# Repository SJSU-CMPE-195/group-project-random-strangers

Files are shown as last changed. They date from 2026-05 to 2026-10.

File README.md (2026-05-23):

# Project Title

> Automatic Dodgeball Turret for Defence and ATTACK!

## Team

| Name | GitHub | Email |
|---|---|---|
| Zoya Shamak | [@ZoyaS](https://github.com/ZoyaS) | zoya.shamak@sjsu.edu |
| Isa Pudiyapura | [@github210878](https://github.com/github210878) | isa.pudiyapura@sjsu.edu |
| Eric Huang | [@eiechuang](https://github.com/eiechuang) | eric.huang01@sjsu.edu |
| Brendan Parvin | [@brendanofawesome](https://github.com/Brendanofawesome) | brendan.parvin@sjsu.edu |

**Advisor:** [Prof. Wencen Wu]

---

# Project Design  

## Problem Statement  

**Dodgeball is a timeless game of skill and agility. We hope to fix that!**  
With our turret, no longer do you need any particular ability in order to:
 - aim and fire dodgeballs at targets
 - automatically defend against incoming dodgeballs using *hit-to-kill* 

## Proof of Concept Scope

Demonstrate a design that includes:

- [ ] **Fully working mechanical system**
    - [ ] Gimbal with control in both yaw and roll orientations
    - [ ] Flywheel-based dodgeball launching system

- [ ] **Control system for setting motor parameters**
    - [ ] Webserver interaction
    - [ ] I2C-based configuration of ESC drivers
    - [ ] Parameters persist across resets

- [ ] **Targeting and firing system**
    - [ ] Webserver integration to select point on screen
    - [ ] Trajectory estimation

---

# Implementation  

## Screenshots  
| Feature | Screenshot |
|---|---|

## Tech Stack

| Description | Category | Technology | Running On |
|---|---|---|---|
| Command and control webserver | Frontend | Next.JS | Jetson |
| Depth Sensing | Sensing | Microsoft Kinect 2 with libfreenect2 | Jetson |
| High Speed BLDC Control | Movement | SimpleFOC | ESCs |

## Getting Started  
 **TODO** Add a tutorial to getting all the parts working :)  

---

## License

This project is licensed under the [LGPLv3 License](www.gnu.org/licenses/lgpl-3.0.en.htm) - see the [LICENSE](LICENSE.md) file for details.

---

*CMPE 195A/B - Senior Design Project | San Jose State University | Spring 2026*

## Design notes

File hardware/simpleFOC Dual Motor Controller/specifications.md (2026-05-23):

# SimpleFOC Dual Motor Controller - Specifications

## Overview
High-performance dual BLDC motor driver with FOC (Field-Oriented Control) algorithm support, designed for applications requiring precise motor control with simultaneous dual-motor operation.

---

## Power Specifications

### Input Power
- **Voltage Range**: 0V - 36V (nominal 36V maximum)
- **Continuous Power**: As determined by thermal dissipation and current limits (IDK)
- **Voltage Input Protection**: 
  - [x] Overvoltage protection (TVS diodes or Zener clamps)
  - [ ] Reverse polarity protection (ideal diode or integrated FET)
  - [ ] Surge suppression for inductive loads

### Current Specifications
- **Continuous Current per Motor**: 35A (per motor pole)
- **Peak Continuous Current**: 64A (per motor pole)
- **Current Sense Method**: integrated low side current sensing per pole
- **Current Limiting**: Software-controlled with adjustable thresholds

### Power Dissipation
- **MOSFET Losses**: 35A * 4mΩ * 2 = 0.28W per pole
- **Thermal Management**: Heat sinks required for continuous high-current operation
- **Thermal Shutdown**: Integrated temperature monitoring with cutoff at 80-85°C

---

## Motor Control Features

### Supported Motor Types
- **Primary**: 3-phase BLDC (Brushless DC) motors
- **Motor Poles**: 2 to 12 pole pairs typical range
- **Motor Power Range**: 0W to 3kW (voltage and current dependent)

### Encoder/Sensor Support
- **Hall Effect Sensors**:
  - Support for all Hall configurations (commutation angles)
  - Automatic Hall state detection and phase alignment
  
- **Encoder Interface**:
  - Dedicated input pins per motor for Hall sensor signals
  - Hardware debouncing (optional RC filters)
  - Software debounce filtering with configurable delay

### Control Algorithms
- **FOC (Field-Oriented Control)**: Primary control mode
- **Commutation**: Hall-based 6-step or smooth vector control
- **Velocity Control**: PID-based speed regulation
- **Current Control**: Inner PID loop for precise current management
- **Position Control**: Incremental position tracking

---

## Hardware Architecture

### Motor Driving Stage (Per Motor)
- **Topology**: 3-phase full-bridge (6-MOSFET inverter)
- **Gate Driver**: discrete high/low-side gate drivers
  - Deadtime compensation to prevent cross-conduction
  - Bootstrap capacitor charging for high-side drivers
  - Shoot-through protection
  
- **Power Semiconductors**:
  - N-channel MOSFETs with low RDS(on) (<4mΩ typical at 25°C)
  - Voltage rating: ≥60V to handle transient spikes
  - Current rating: ≥50A continuous (per phase)

### Current Sensing (Per Motor)
- **Method**: Low-side shunt resistor sensing
- **Shunt Resistance**: Typical 0.001Ω - 0.01Ω (precision resistor ±1%)
- **Current Signal Processing**:
  - Op-amp based amplification and filtering
  - Signal level conversion to ADC-compatible range (0-3.3V)
  - DC offset rejection and noise filtering

### Hall Sensor Interface
- **Input Impedance**: High impedance (pull-up to 3.3V or 5V)
- **Debouncing**: Hardware (RC filter, typically 1-10µs time constant)
- **Signal Conditioning**: Schmitt trigger inputs for noise immunity
- **Per-Motor Configuration**: Independent hall input pins for dual-motor operation

### Microcontroller/Controller Board
- **Integrated Microcontroller**: 
  - **STM32G4 Series**: Cost-effective FOC control with sufficient processing power for dual motor management

### Power Distribution
- **Input Filtering**:
  - Bulk capacitance: 220µF @ 100V
  - High-frequency ceramic capacitors: 10uF x 12
  - LC filtering for noise reduction
  
- **Voltage Rails**:
  - Main power bus: +36V (directly from input)
  - Logic supply: +5V
  - Gate driver supply: 10V Charge Pump

---

## Electrical Specifications

### Output Specifications (Per Motor)
- **Output Voltage**: 0V - VIN (PWM modulated)
- **Frequency**: 16-20 kHz typical (configurable)
- **Phase Current Range**: 0A - 35A (continuous)

### Protection Features
- **Over-Current Protection**: Software-programmable limits per motor
- **Over-Temperature**: Thermal shutdown with hysteresis
- **Phase Fault Detection**: Open-phase or short-circuit detection
- **Under-voltage Lockout**: Prevents operation below safe voltage threshold
- **Over-voltage Clamping**: TVS diodes on phase outputs

### Control Signals
- **PWM Frequency**: 16-20 kHz (20-25 kHz for low audible noise)
- **Deadtime**: 50-200ns (tunable to minimize losses and cross-conduction)
- **Switching Resolution**: 12-bit typical (configurable)

---

## Communication Interface

### I2C Slave Interface
- **Protocol**: I2C slave
- **Clock Speed**: Up to 800 kHz (configurable)
- **Data Width**: 8-bit transfers
- **Features**:
  - Real-time motor control commands
  - Telemetry readback (speed, current, temperature)
  - Parameter configuration and tuning
  - Fault/diagnostic reporting and clearing
  - Low latency (<1ms round-trip response)

### Backup Communication
- **USB Debug Port**: 115200 baud for development/debugging only
- **Protocol**: UART for system diagnostics

### Configuration
- **Parameter Storage**: Flash memory for persistent settings
- **Firmware Updates**: Via USB interface with checksumming
- **Startup Calibration**: Automated hall sensor calibration on power-up or via SPI command

---

## Performance Specifications

### Control Performance
- **Current Control Loop Frequency**: 10-20 kHz
- **Velocity Control Loop Frequency**: 1-5 kHz (configurable)
- **Current Ripple**: <5% at rated current
- **Efficiency**: >90% at rated current (at 36V input)

### Sensor Performance
- **Hall Sensor Polling Rate**: 20 kHz minimum
- **Hall-to-PWM Update Latency**: <100µs
- **Motor Startup Time**: <500ms from initialization to controlled rotation

---

## Thermal Management

### Temperature Monitoring
- **Sensor Location**: On heatsink or MOSFET thermal pad
- **Temperature Range (Operating)**: -10°C to +85°C
- **Temperature Range (Storage)**: -20°C to +100°C
- **Thermal Shutdown**: 80-85°C (with 5-10°C hysteresis)

### Cooling Requirements
- **Passive Cooling**: Adequate heatsinks for 35A continuous operation
- **Active Cooling**: Optional fan control for high-duty-cycle applications
- **Thermal Design**: Capable of dissipating >600W continuously

---

## Physical and Mechanical

### PCB Design
- **Layer Count**: 4-layer minimum (power, ground planes essential)
- **Trace Width**: Calculated for 35A+ with <10mV drop per phase
- **Thermal Vias**: Liberally used under MOSFET pads and power components
- **Isolation**: 3kV reinforced isolation between control and power sections (optional)

### Connector Standards
- **Power Input**: High-current connector (XT60, XT90, or Anderson PowerPole)
- **Motor Output**: 3.5mm or 5mm phoenix connectors per motor
- **Hall Sensors**: JST-XH or similar low-current connectors (6 pins per motor)
- **Communication**: USB micro-B or UART header

### Dimensions
- **Target Size**: ~150mm × 100mm × 50mm (estimated, depends on heatsink size)
- **Weight**: <500g (without heatsink)

---

## Software Architecture

### Firmware Platform
- **Framework**: simpleFOC library v2.3+ with dual-motor support
- **Development Language**: C/C++

### Core Control Loop
- **Execution**: Hardware timer interrupt (20 kHz)
- **Tasks**:
  1. Read hall sensor states
  2. Estimate rotor angle via sensor fusion
  3. Calculate FOC voltage vectors
  4. Update PWM outputs
  5. Log telemetry (if enabled)

### Tuning Parameters
- **PID Gains** (per motor):
  - Current loop: Kp, Ki (typically Kp=10-50, Ki=100-500)
  - Velocity loop: Kp, Ki, Kd
- **Motor Parameters**: Pole pairs, voltage rating, current rating
- **Hall Configuration**: Specific angle mapping for hall state transitions

---

## Compliance and Safety

### Electrical Safety
- **Isolation**: Optional galvanic isolation between control and power circuits
- **Fusing**: Input fuse rated for 40-50A @ 48V (protection from short-circuit)
- **Creepage/Clearance**: PCB design follows IEC standards

### Functional Safety
- **Watchdog Timer**: Monitors firmware execution and resets on timeout
- **Redundant Checks**: Current and temperature limits with independent enforcement
- **Fault Reporting**: Detailed error codes for diagnostics and debugging

---

## Typical Applications

- Dual-axis robotic actuators
- Autonomous vehicle drive systems
- High-performance drone motors
- Gimbal stabilization systems
- Industrial automation drives

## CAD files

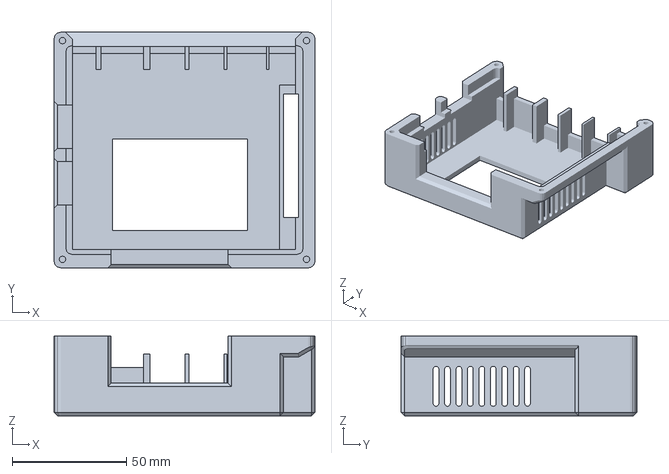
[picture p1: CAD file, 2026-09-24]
hardware/3D Models/Jetson/Orin_nano_case_main_No_CAN_No inserts.3MF
114.0 x 103.0 x 34.8 mm

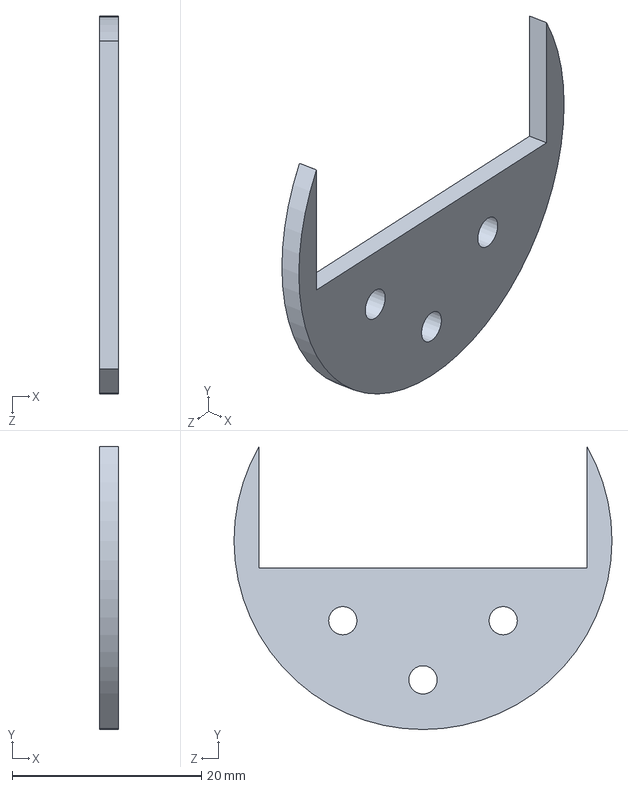
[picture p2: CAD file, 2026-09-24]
hardware/3D Models/Gimbal/3d_printed - depreciated/Magnet Plate Spacer.SLDPRT
2.00 x 29.9 x 40.0 mm

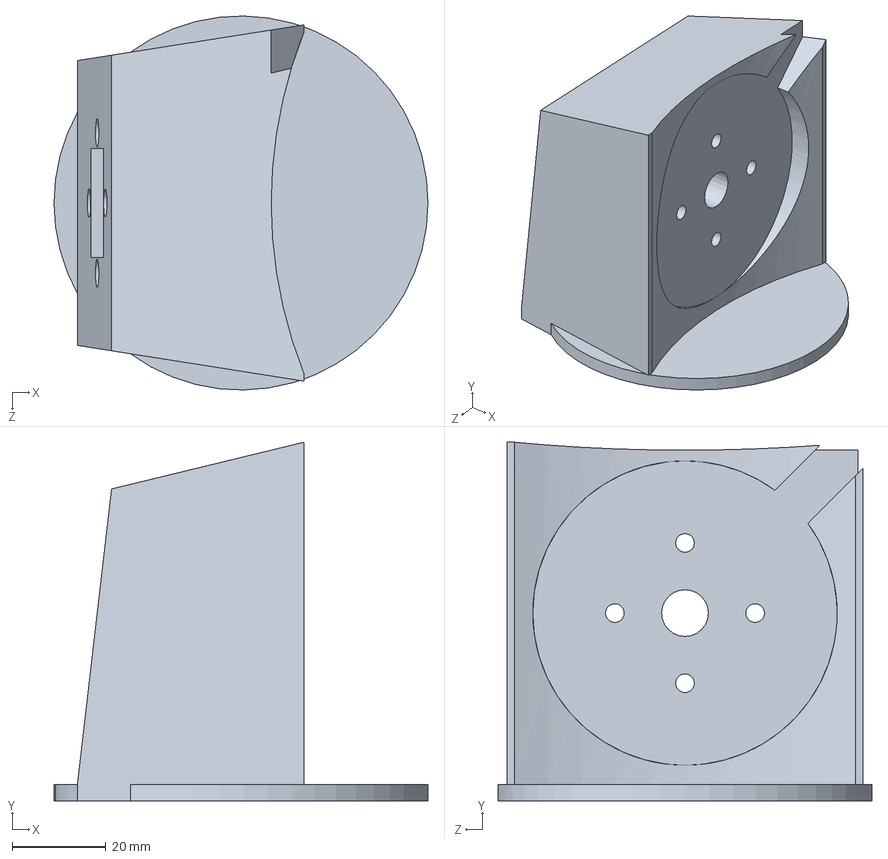
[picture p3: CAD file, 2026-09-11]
hardware/3D Models/Gimbal/Test Stands/Pitch Motor Test Stand.SLDPRT
80.0 x 76.7 x 80.0 mm

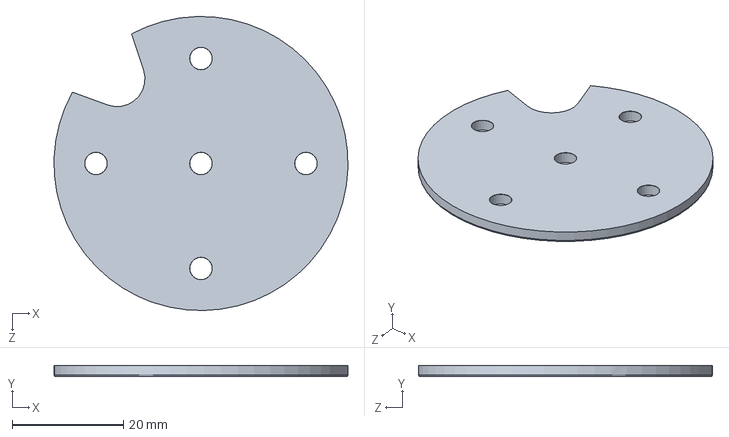
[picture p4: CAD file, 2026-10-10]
hardware/3D Models/Gimbal/wood/Slip Ring Hole Guide.SLDPRT
52.8 x 2.00 x 52.8 mm

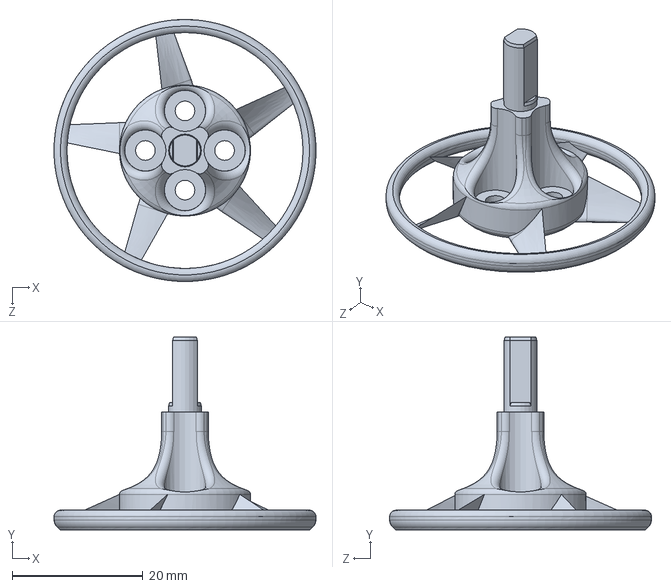
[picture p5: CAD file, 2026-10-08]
hardware/3D Models/Launcher/Flywheels/Flywheel Wheel Mount.SLDPRT
40.0 x 29.4 x 40.0 mm

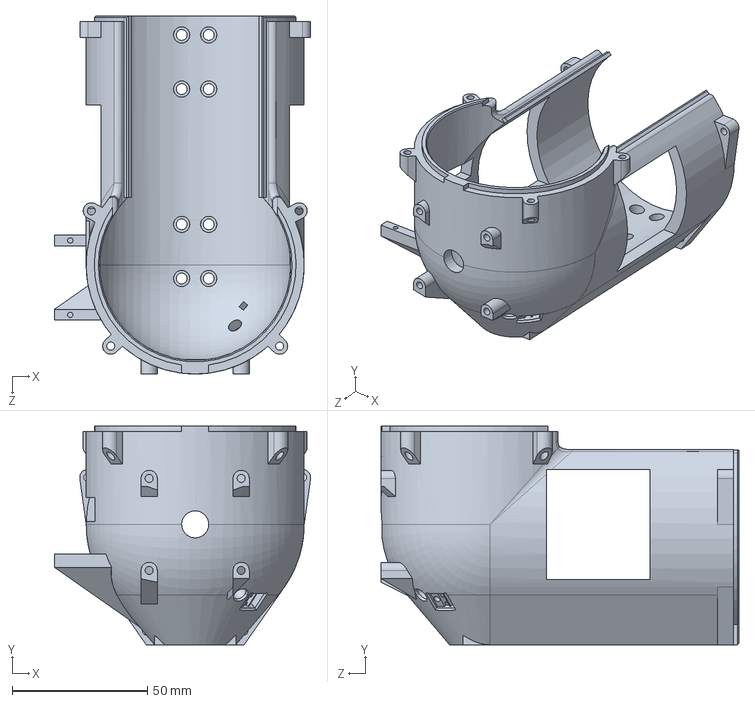
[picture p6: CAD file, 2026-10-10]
hardware/3D Models/Launcher/Load Mechanism/Stager.SLDPRT
94.7 x 80.8 x 132.3 mm

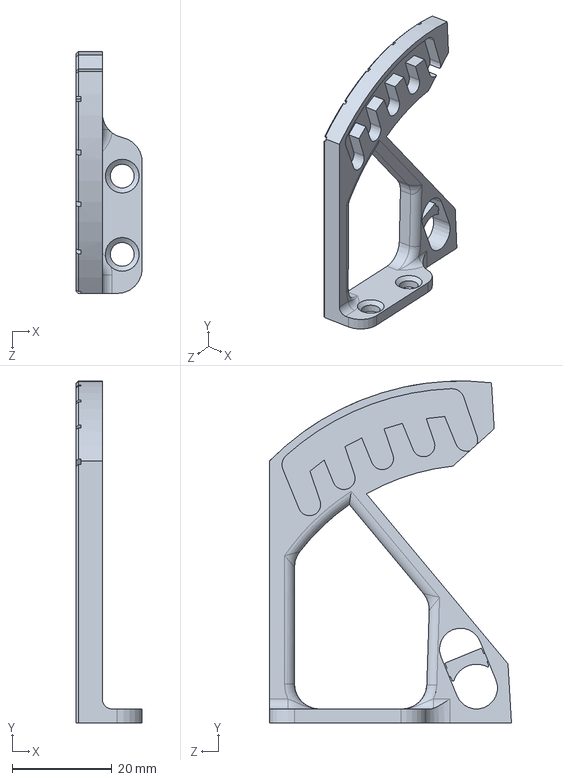
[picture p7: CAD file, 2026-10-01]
hardware/3D Models/Mounts/Zed Mount/Zed Angle Guage.SLDPRT
13.3 x 68.4 x 48.4 mm

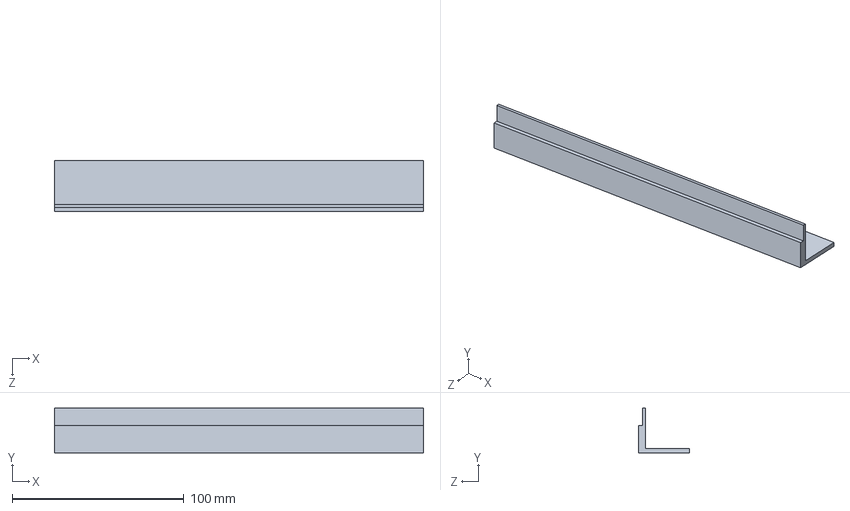
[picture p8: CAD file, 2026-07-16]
hardware/3D Models/Power Supply/Power Supply.SLDPRT
215.0 x 26.0 x 30.0 mm

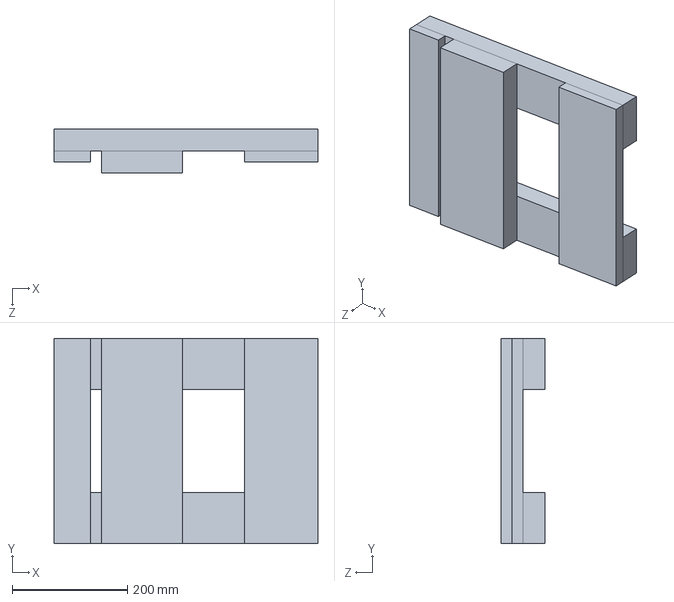
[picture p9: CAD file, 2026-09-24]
hardware/3D Models/Base.SLDPRT
457.2 x 355.6 x 76.2 mm

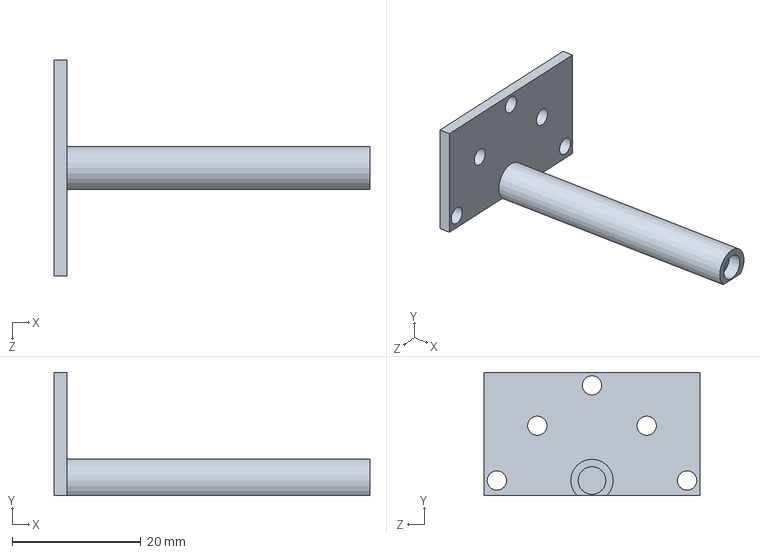
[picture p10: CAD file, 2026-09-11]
hardware/3D Models/Gimbal/3d_printed - depreciated/Pitch Motor Magnet Plate.SLDPRT
49.0 x 19.1 x 33.5 mm

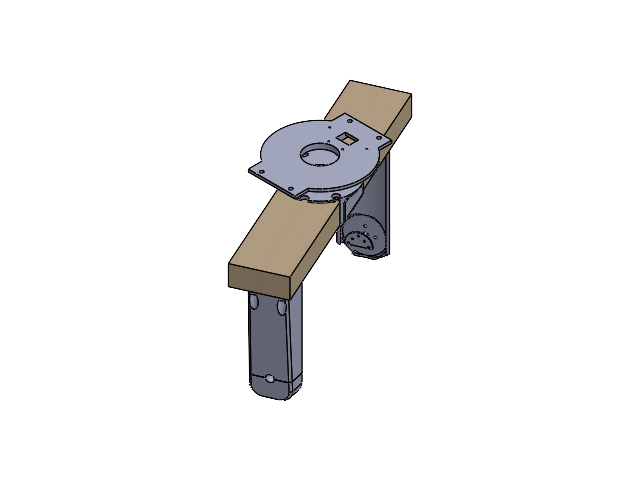
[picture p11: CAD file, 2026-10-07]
hardware/3D Models/Gimbal/Gimbal.SLDASM
Gimbal Base
Yaw Flush Plate
Yaw Beam
Pitch Motor Magnet Plate - wood
Pitch Mount - Bearing
Pitch Mount - Motor

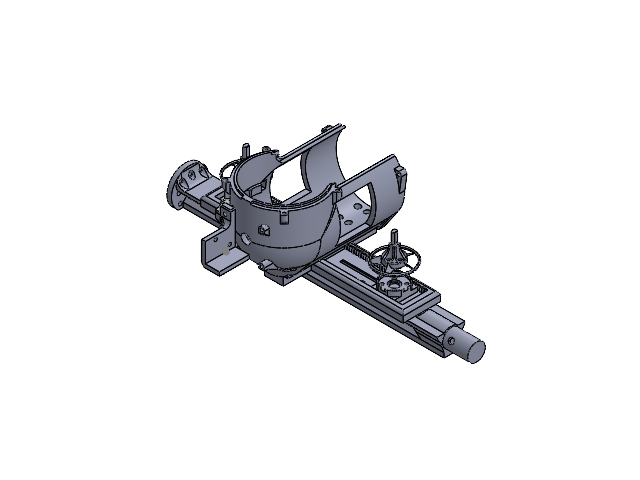
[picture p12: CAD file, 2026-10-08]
hardware/3D Models/Launcher/Launcher Assembly.SLDASM
Launcher I-Beam Mount
Bearing End Mount^Launcher Assembly
Flywheel Rail
Flywheel Motor Mount x 2
Stager
SG90 - Micro Servo 9g - Tower Pro.1_Pe_a.STEP
Loader Stop
Solenoid Mount
Flywheel Wheel Mount
MirrorFlywheel Wheel Mount

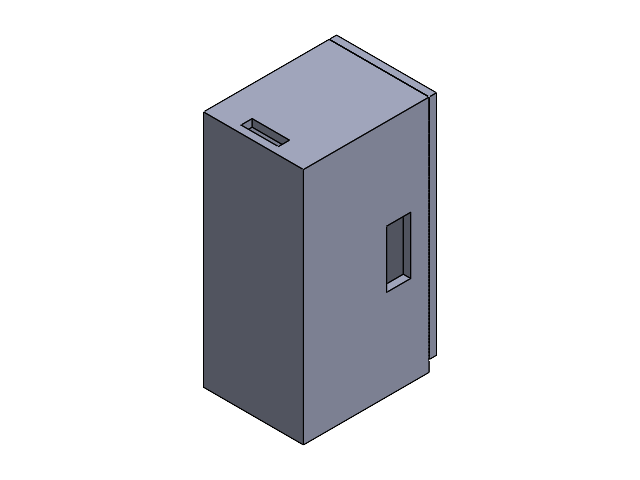
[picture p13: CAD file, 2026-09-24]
hardware/3D Models/Mounts/Yaw Motor/Yaw Motor Box.SLDASM
Box Bottom
Box Top

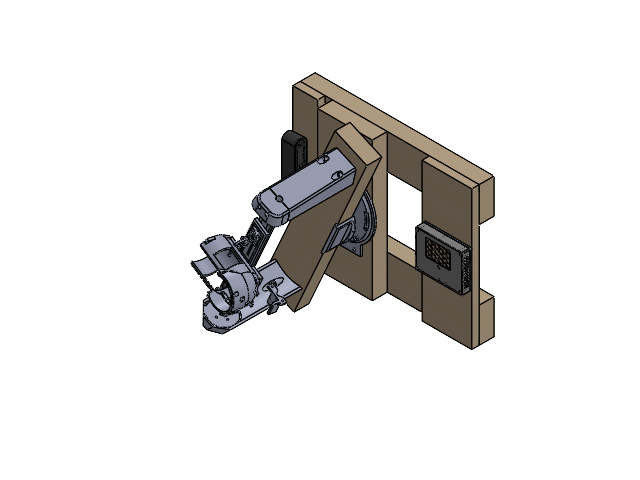
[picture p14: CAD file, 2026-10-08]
hardware/3D Models/Turret.SLDASM
Base
DSL958R-650-F2.0 -光锥图.step x 2
Narrow lens 4.6mm.step x 2
Right Lens Holder.step x 2
PCB ZED2i.step
USB Type C Port.step
Front case - ZED 2i.step
Rear case - ZED 2i.step
Camera Component - Body - ZED 2i - 4.6mm - Cover.step
Gimbal Base
Yaw Flush Plate
Yaw Beam
Pitch Motor Magnet Plate - wood
Pitch Mount - Bearing
Pitch Mount - Motor
orin-nano-case-base.step
orin-nano-case-top.step
Launcher I-Beam Mount
Bearing End Mount^Launcher Assembly
Flywheel Rail
Flywheel Motor Mount x 2
Stager
SG90 - Micro Servo 9g - Tower Pro.1_Pe_a.STEP
Loader Stop
Solenoid Mount
Flywheel Wheel Mount x 2

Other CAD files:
hardware/3D Models/Gimbal/3d_printed - depreciated/Gimbal Assembly.SLDASM
hardware/3D Models/Launcher/Load Mechanism/Loader Assembly.SLDASM
hardware/3D Models/Mounts/Zed Mount/Zed Mount.SLDASM
hardware/3D Models/Launcher/Flywheels/Flywheel Assembly.SLDASM
hardware/3D Models/Gimbal/3d_printed - depreciated/Gimbal Pivot Holder.SLDPRT
hardware/3D Models/Gimbal/3d_printed - depreciated/Gimbal Swivel.SLDPRT
hardware/3D Models/Gimbal/Gimbal Base.SLDPRT
hardware/3D Models/Gimbal/wood/Gimbal Bearing Mount Bottom.SLDPRT
hardware/3D Models/Gimbal/wood/Gimbal Bearing Mount Top.SLDPRT
hardware/3D Models/Gimbal/wood/Pitch Motor Magnet Plate - wood.SLDPRT
hardware/3D Models/Gimbal/wood/Pitch Mount - Bearing Bottom.SLDPRT
hardware/3D Models/Gimbal/wood/Pitch Mount - Bearing.SLDPRT
hardware/3D Models/Gimbal/wood/Pitch Mount - Motor.SLDPRT
hardware/3D Models/Gimbal/wood/Yaw Beam.SLDPRT
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

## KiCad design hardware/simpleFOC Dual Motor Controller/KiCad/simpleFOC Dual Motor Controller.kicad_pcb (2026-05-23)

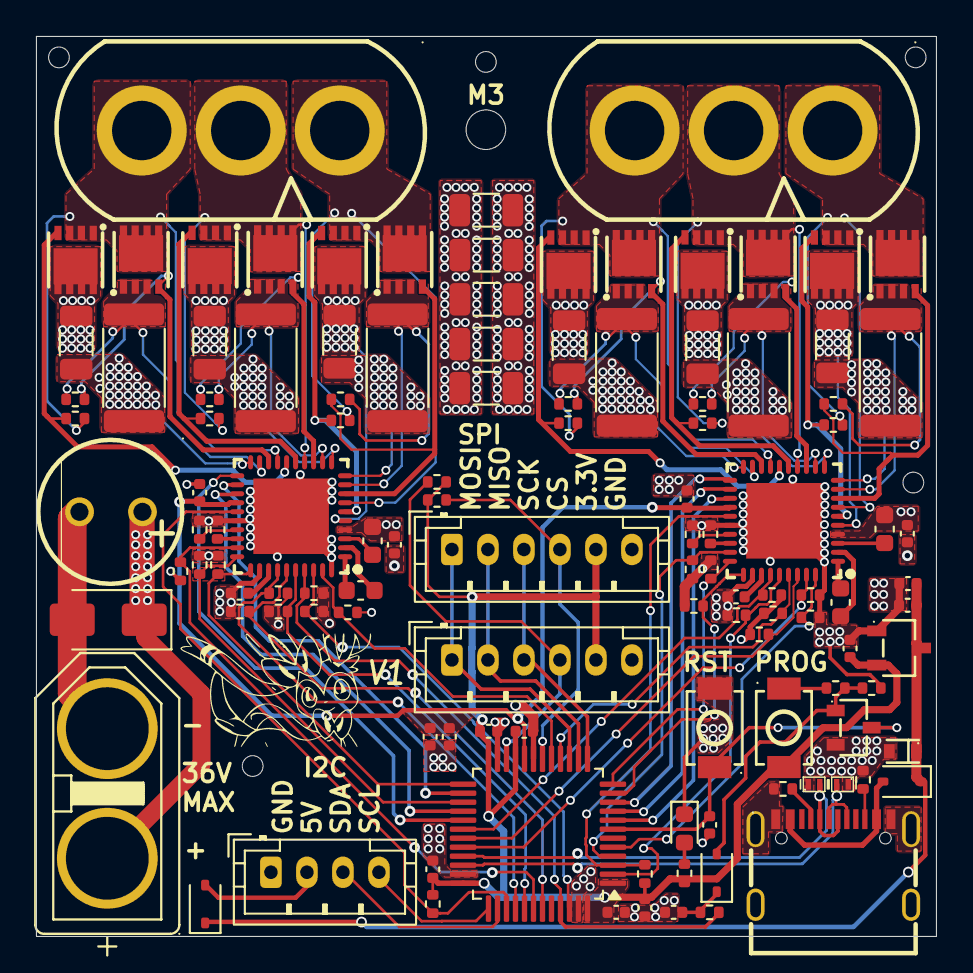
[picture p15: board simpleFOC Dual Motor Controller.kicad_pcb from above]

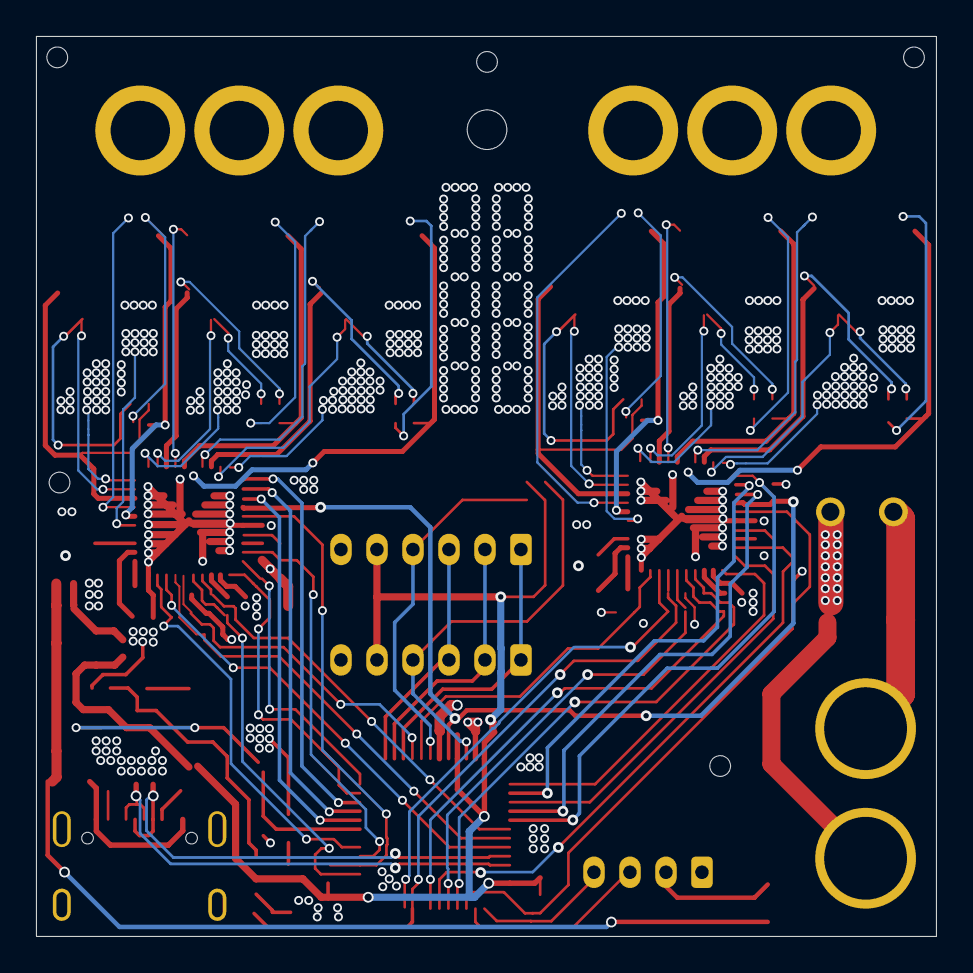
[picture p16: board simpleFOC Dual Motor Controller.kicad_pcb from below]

Board: 4 copper layers, 50.0 x 50.0 mm, 130 parts (6 on the bottom side), 91 nets.

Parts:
C101: 220u; CAP-TH_BD8.0-P3.50-D0.6-FD
C102, C115: 4.7u; C_0402_1005Metric
C103, C104, C106, C107, C113, C201, C205, C206, C209: 100n; C_0402_1005Metric
C105, C112, C114, C204, C210: 1u; C_0402_1005Metric
C108, C109, C110, C117, C118, C119, C120, C121, C301, C401, C501: 10u; C_1206_3216Metric
C111: 10n; C_0402_1005Metric
C116: 220n; C_0402_1005Metric
C202, C207: 1u; C_0603_1608Metric
C203, C208: 47n; C_0603_1608Metric
CN101: XT60PB-F.G.Y; CONN-TH_XT60PB-F.G.Y
CN201, CN202: MR60-F; CONN-TH_3P-P5.50_MR60-F
D101: SMAJ36A; D_SMA
D102, D104, D107: 1N5819WS; D_SOD-323
D103, D105: H5VL10B; SOD-882_L1.0-W0.6-BI
D106: LED; LED_0603_1608Metric
H101, H102, H103, H104, H107: MountingHole; JLC_Tooling_Hole
H105: MountingHole; MountingHole_2.2mm_M2
J101: Conn_01x04; JST_PH_B4B-PH-K_1x04_P2.00mm_Vertical
J103, J104: Conn_01x06; JST_PH_B6B-PH-K_1x06_P2.00mm_Vertical
J105: USB-TYPE-C-019; TYPE-C-SMD_HX-TYPE-C-16PIN
NT201, NT202, NT203, NT204, NT205, NT206: NetTie_2; NetTie0.127mm
Q101: AO3400A; SOT-23-3_L2.9-W1.3-P1.90-LS2.4-BR
Q301, Q302, Q401, Q402, Q501, Q502, Q701, Q702, Q801, Q802, Q901, Q902: XRS100N06LD; DFN-8_L3.0-W3.0-P0.65-BL-4
R101, R102, R103, R104, R105, R106, R223, R301, R302, R401, R402, R501, R502, R601: 47k; R_0402_1005Metric
R107, R108: 5.1k; R_0402_1005Metric
R109, R113: 3.3k; R_0402_1005Metric
R110, R111, R112, R203, R204, R205, R206, R207, R208, R209, R210, R211, R214, R215, R216, R220, R221, R222, R602, R603, R604: 100k; R_0402_1005Metric
R114: 330; R_0402_1005Metric
R201, R213: 18k; R_0402_1005Metric
R202, R212: 75k; R_0402_1005Metric
Rsns101, Rsns102, Rsns103, Rsns301, Rsns401, Rsns501: 0.002; R_2512_6332Metric
SW101, SW102: TS-1088-AR02016; SW-SMD_L3.9-W3.0-P4.45
U101: XC6206P332MR; SOT-23-3_L2.9-W1.6-P1.90-LS2.8-BR
U103: STM32G474CBTx; LQFP-48_7x7mm_P0.5mm
U104: H5VND5UB; SOD-523F_L1.7-W0.9-LS1.7-RD
U201, U202: DRV8323HRTAT; WQFN-40_L6.0-W6.0-P0.50-TL-EP4.2

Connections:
+3.3V: C103.1, C104.1, C106.1, C107.1, C112.1, C115.1, J103.5, J104.5, R110.2, R111.2, R114.1, R211.2, R222.2, SW102.1, U101.2 (Vout), U103.1 (VBAT), U103.21 (VDDA), U103.24 (VDD), U103.36 (VDD), U103.48 (VDD)
+5V: C102.1, C105.1, D102.1 (K), D107.1 (K), U101.3 (Vin), U104.1 (K)
/CAL1: R210.1, U103.11 (PA3), U201.31 (CAL)
/CAL2: R221.1, U103.25 (PB11), U202.31 (CAL)
/CHA1: R203.1, U103.30 (TIM1_CH1), U201.34 (INHA)
/CHA2: R214.1, U103.40 (TIM8_CH1N), U202.34 (INHA)
/CHB1: R204.1, U103.16 (TIM1_CH2N), U201.36 (INHB)
/CHB2: R215.1, U103.41 (TIM8_CH2N), U202.36 (INHB)
/CHC1: R205.1, U103.32 (TIM1_CH3), U201.38 (INHC)
/CHC2: R216.1, U103.46 (TIM8_CH3), U202.38 (INHC)
/CHLA1: R206.1, U103.2 (TIM1_CH1N), U201.35 (INLA)
/CHLA2: R602.1, U103.43 (TIM8_CH1), U202.35 (INLA)
/CHLB1: R207.1, U103.31 (TIM1_CH2), U201.37 (INLB)
/CHLB2: R109.1, R603.1, U103.45 (TIM8_CH2), U202.37 (INLB)
/CHLC1: R208.1, U103.5 (TIM1_CH3N), U201.39 (INLC)
/CHLC2: R604.1, U103.17 (TIM8_CH3N), U202.39 (INLC)
/D+: D103.2 (A), J105.A6 (D+), J105.B6 (D+), U103.34 (USB_DP)
/D-: D105.2 (A), J105.A7 (D-), J105.B7 (D-), U103.33 (USB_DM)
/EN1: R209.1, U103.12 (PA4), U201.30 (ENABLE)
/EN2: R220.1, U103.27 (PB13), U202.30 (ENABLE)
/FAULT1: R211.1, U103.3 (PC14), U201.25 (nFAULT)
/FAULT2: R222.1, U103.39 (PA15), U202.25 (nFAULT)
/GAIN1: R223.1, U103.4 (PC15), U201.29 (GAIN)
/GAIN2: R601.1, U103.42 (PB5), U202.29 (GAIN)
/Motor Driver 1/DVDD: C204.1, U201.33 (DVDD)
/Motor Driver 1/Pole 1/GH: Q302.4 (G), R302.1, U201.6 (GHA)
/Motor Driver 1/Pole 1/GL: Q301.4 (G), R301.1, U201.8 (GLA)
/Motor Driver 1/Pole 1/PoleOut: CN201.1, Q301.5 (D), Q302.1 (S), Q302.2 (S), Q302.3 (S), R302.2, U201.7 (SHA)
/Motor Driver 1/Pole 1/SP: Q301.1 (S), Q301.2 (S), Q301.3 (S), R301.2, Rsns301.1, U201.9 (SPA)
/Motor Driver 1/Pole 2/GH: Q402.4 (G), R402.1, U201.15 (GHB)
/Motor Driver 1/Pole 2/GL: Q401.4 (G), R401.1, U201.13 (GLB)
/Motor Driver 1/Pole 2/PoleOut: CN201.2, Q401.5 (D), Q402.1 (S), Q402.2 (S), Q402.3 (S), R402.2, U201.14 (SHB)
/Motor Driver 1/Pole 2/SP: Q401.1 (S), Q401.2 (S), Q401.3 (S), R401.2, Rsns401.1, U201.12 (SPB)
/Motor Driver 1/Pole 3/GH: Q502.4 (G), R502.1, U201.16 (GHC)
/Motor Driver 1/Pole 3/GL: Q501.4 (G), R501.1, U201.18 (GLC)
/Motor Driver 1/Pole 3/PoleOut: CN201.3, Q501.5 (D), Q502.1 (S), Q502.2 (S), Q502.3 (S), R502.2, U201.17 (SHC)
/Motor Driver 1/Pole 3/SP: Q501.1 (S), Q501.2 (S), Q501.3 (S), R501.2, Rsns501.1, U201.19 (SPC)
/Motor Driver 2/DVDD: C210.1, U202.33 (DVDD)
/Motor Driver 2/Pole 1/GH: Q701.4 (G), R101.1, U202.6 (GHA)
/Motor Driver 2/Pole 1/GL: Q702.4 (G), R104.1, U202.8 (GLA)
/Motor Driver 2/Pole 1/PoleOut: CN202.1, Q701.1 (S), Q701.2 (S), Q701.3 (S), Q702.5 (D), R101.2, U202.7 (SHA)
/Motor Driver 2/Pole 1/SP: Q702.1 (S), Q702.2 (S), Q702.3 (S), R104.2, Rsns101.1, U202.9 (SPA)
/Motor Driver 2/Pole 2/GH: Q901.4 (G), R102.1, U202.15 (GHB)
/Motor Driver 2/Pole 2/GL: Q902.4 (G), R105.1, U202.13 (GLB)
/Motor Driver 2/Pole 2/PoleOut: CN202.2, Q901.1 (S), Q901.2 (S), Q901.3 (S), Q902.5 (D), R102.2, U202.14 (SHB)
/Motor Driver 2/Pole 2/SP: Q902.1 (S), Q902.2 (S), Q902.3 (S), R105.2, Rsns102.1, U202.12 (SPB)
/Motor Driver 2/Pole 3/GH: Q801.4 (G), R103.1, U202.16 (GHC)
/Motor Driver 2/Pole 3/GL: Q802.4 (G), R106.1, U202.18 (GLC)
/Motor Driver 2/Pole 3/PoleOut: CN202.3, Q801.1 (S), Q801.2 (S), Q801.3 (S), Q802.5 (D), R103.2, U202.17 (SHC)
/Motor Driver 2/Pole 3/SP: Q802.1 (S), Q802.2 (S), Q802.3 (S), R106.2, Rsns103.1, U202.19 (SPC)
/VREF: C113.1, C114.1, C205.1, C209.1, U103.20 (VREFBUF_OUT), U201.24 (VREF), U202.24 (VREF)
/ctrl_scl: J101.4, U103.37 (I2C1_SCL)
/ctrl_sda: J101.3, U103.38 (I2C1_SDA)
/snsA1: U103.8 (ADC1_IN1), U201.23 (SOA)
/snsA2: U103.28 (PB14), U202.23 (SOA)
/snsB1: U103.9 (ADC1_IN2), U201.22 (SOB)
/snsB2: U103.26 (PB12), U202.22 (SOB)
/snsC1: U103.10 (ADC1_IN3), U201.21 (SOC)
/snsC2: U103.29 (PB15), U202.21 (SOC)
/sns_cs1: J104.4, R110.1, U103.22 (PB10)
/sns_cs2: J103.4, R111.1, U103.18 (PB2)
/sns_miso: J103.2, J104.2, U103.14 (SPI1_MISO)
/sns_mosi: J103.1, J104.1, U103.15 (SPI1_MOSI)
/sns_sck: J103.3, J104.3, U103.13 (SPI1_SCK)
/~rst: C111.1, Q101.3 (D), SW101.2, U103.7 (PG10)
GND: C101.2, C102.2, C103.2, C104.2, C105.2, C106.2, C107.2, C108.2, C109.2, C110.2, C111.2, C112.2, C113.2, C114.2, C115.2, C116.2, C117.2, C118.2, C119.2, C120.2, C121.2, C201.2, C204.2, C205.2, C206.2, C209.2, C210.2, C301.2, C401.2, C501.2, CN101.-, D101.2 (A2), D103.1 (C), D105.1 (C), D106.1 (K), J101.1, J103.6, J104.6, J105.17 (SHIELD), J105.A12B1 (GND), J105.B12A1 (GND), NT201.2, NT202.2, NT203.2, NT204.2, NT205.2, NT206.2, Q101.2 (S), R107.2, R108.2, R112.1, R201.2, R202.2, R203.2, R204.2, R205.2, R206.2, R207.2, R208.2, R209.2, R210.2, R212.2, R213.2, R214.2, R215.2, R216.2, R220.2, R221.2, R223.2, R601.2, R602.2, R603.2, R604.2, Rsns101.2, Rsns102.2, Rsns103.2, Rsns301.2, Rsns401.2, Rsns501.2, SW101.1, U101.1 (GND), U103.19 (VSSA), U103.23 (VSS), U103.35 (VSS), U103.47 (VSS), U104.2 (A), U201.26 (MODE), U201.32 (AGND), U201.40 (PGND), U201.41 (EP), U202.26 (MODE), U202.32 (AGND), U202.40 (PGND), U202.41 (EP)
M+: C101.1, C108.1, C109.1, C110.1, C117.1, C118.1, C119.1, C120.1, C121.1, C201.1, C202.1, C206.1, C207.1, C301.1, C401.1, C501.1, CN101.+, D101.1 (A1), Q302.5 (D), Q402.5 (D), Q502.5 (D), Q701.5 (D), Q801.5 (D), Q901.5 (D), U201.4 (VM), U201.5 (VDRAIN), U202.4 (VM), U202.5 (VDRAIN)
unnamed: D102.2 (A), J105.A9B4 (VBUS), J105.B9A4 (VBUS)
unnamed: D104.2 (A), Q101.1 (G), R112.2, R113.1
unnamed: C116.1, D104.1 (K), R109.2
unnamed: D106.2 (A), R114.2
unnamed: D107.2 (A), J101.2
unnamed: J105.A5 (CC1), R107.1
unnamed: J105.B5 (CC2), R108.1
unnamed: R113.2, SW102.2
unnamed: C203.1, U201.2 (CPH)
unnamed: C203.2, U201.1 (CPL)
unnamed: R201.1, U201.27 (IDRIVE)
unnamed: NT201.1, U201.10 (SNA)
unnamed: NT202.1, U201.11 (SNB)
unnamed: NT203.1, U201.20 (SNC)
unnamed: C202.2, U201.3 (VCP)
unnamed: R202.1, U201.28 (VDS)
unnamed: C208.1, U202.2 (CPH)
unnamed: C208.2, U202.1 (CPL)
unnamed: R213.1, U202.27 (IDRIVE)
unnamed: NT204.1, U202.10 (SNA)
unnamed: NT205.1, U202.11 (SNB)
unnamed: NT206.1, U202.20 (SNC)
unnamed: C207.2, U202.3 (VCP)
unnamed: R212.1, U202.28 (VDS)

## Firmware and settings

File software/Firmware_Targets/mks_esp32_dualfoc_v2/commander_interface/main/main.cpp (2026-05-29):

#include "../../board_config.h"

#include "freertos/FreeRTOS.h"
#include "freertos/task.h"

#include "esp_err.h"
#include "esp_timer.h"

#include <math.h>

#include <esp_simplefoc.h>
#include <MXLEMMINGObserverSensor.h>
#include <current_sense/InlineCurrentSense.h>

// User parameters
#define DISABLE_ENCODERS 1
#define DISABLE_MXLEMMING_OBSERVER 1
#define DISABLE_CURRENT_SENSE 0
#define DISABLE_MOTOR_0 1
#define DISABLE_MOTOR_1 0

static constexpr float USER_MAX_MOTOR_VOLTAGE = 15.0f;
static constexpr float USER_MAX_MOTOR_CURRENT = 1.0f;

// Observer attach/detach thresholds.
// Detach below the lower threshold.
// Reattach above the upper threshold.
// This hysteresis prevents rapid attach/detach toggling near the cutoff.
static constexpr float OBSERVER_DETACH_VELOCITY = 20.0f;
static constexpr float OBSERVER_ATTACH_VELOCITY = 40.0f;

static constexpr int MOTOR0_POLE_PAIRS = 12;
static constexpr float MOTOR0_RESISTANCE = 9.2f;
static constexpr float MOTOR0_PHASE_INDUCTANCE = 0.001f;
static constexpr float MOTOR0_KV = 30.0f;

static constexpr int MOTOR1_POLE_PAIRS = 12;
static constexpr float MOTOR1_RESISTANCE = 9.2f;
static constexpr float MOTOR1_PHASE_INDUCTANCE = 0.001f;
static constexpr float MOTOR1_KV = 30.0f;

// Dedicated timer periods
static constexpr uint64_t FOC_PERIOD_US = 50;          // 20 kHz
static constexpr uint64_t MOVEMENT_PERIOD_US = 75;    // 20 kHz
static constexpr uint64_t COMMANDER_PERIOD_US = 10000; // 100 Hz

Commander commander = Commander(Serial);

static esp_timer_handle_t foc_timer = nullptr;
static esp_timer_handle_t movement_timer = nullptr;
static esp_timer_handle_t commander_timer = nullptr;

#if !DISABLE_MOTOR_0
	static char motor0_label[] = "motor0";

	BLDCMotor motor0(
		MOTOR0_POLE_PAIRS,
		MOTOR0_RESISTANCE,
		MOTOR0_KV,
		MOTOR0_PHASE_INDUCTANCE
	);

	BLDCDriver3PWM driver0(
		BOARD_MOTOR_A0,
		BOARD_MOTOR_B0,
		BOARD_MOTOR_C0,
		BOARD_MOTOR_EN0
	);

	#if BOARD_CURRENT_SENSE_TYPE == 0 && !DISABLE_CURRENT_SENSE
		InlineCurrentSense currentSense0(
			BOARD_CURRENT_SENSE_RESISTANCE,
			BOARD_CURRENT_SENSE_GAIN,
			BOARD_CURRENT_SENSE_A0,
			BOARD_CURRENT_SENSE_B0
		);
	#endif

	#if !DISABLE_ENCODERS
		HallSensor hall0(
			BOARD_HALL_U0,
			BOARD_HALL_V0,
			BOARD_HALL_W0,
			MOTOR0_POLE_PAIRS
		);

		void doHall0A() { hall0.handleA(); }
		void doHall0B() { hall0.handleB(); }
		void doHall0C() { hall0.handleC(); }
	#elif !DISABLE_MXLEMMING_OBSERVER
		MXLEMMINGObserverSensor observer0(motor0);
		static bool observer0_attached = false;
	#endif

	void doMotor0(char* cmd) {
		commander.motor(&motor0, cmd);
	}
#endif

#if !DISABLE_MOTOR_1
	static char motor1_label[] = "motor1";

	BLDCMotor motor1(
		MOTOR1_POLE_PAIRS,
		MOTOR1_RESISTANCE,
		MOTOR1_KV,
		MOTOR1_PHASE_INDUCTANCE
	);

	BLDCDriver3PWM driver1(
		BOARD_MOTOR_A1,
		BOARD_MOTOR_B1,
		BOARD_MOTOR_C1,
		BOARD_MOTOR_EN1
	);

	#if BOARD_CURRENT_SENSE_TYPE == 0 && !DISABLE_CURRENT_SENSE
		InlineCurrentSense currentSense1(
			BOARD_CURRENT_SENSE_RESISTANCE,
			BOARD_CURRENT_SENSE_GAIN,
			BOARD_CURRENT_SENSE_A1,
			BOARD_CURRENT_SENSE_B1
		);
	#endif

	#if !DISABLE_ENCODERS
		HallSensor hall1(
			BOARD_HALL_U1,
			BOARD_HALL_V1,
			BOARD_HALL_W1,
			MOTOR1_POLE_PAIRS
		);

		void doHall1A() { hall1.handleA(); }
		void doHall1B() { hall1.handleB(); }
		void doHall1C() { hall1.handleC(); }
	#elif !DISABLE_MXLEMMING_OBSERVER
		MXLEMMINGObserverSensor observer1(motor1);
		static bool observer1_attached = false;
	#endif

	void doMotor1(char* cmd) {
		commander.motor(&motor1, cmd);
	}
#endif


#if !DISABLE_MOTOR_0 && DISABLE_ENCODERS && !DISABLE_MXLEMMING_OBSERVER
static void update_motor0_observer_attachment() {
	const float velocity = observer1_attached
		? fabsf(motor0.shaft_velocity)
		: fabsf(motor0.target); // replace with requested velocity if target is not velocity

	if (observer0_attached && velocity < OBSERVER_DETACH_VELOCITY) {
		motor0.linkSensor(nullptr);
		observer0_attached = false;
		return;
	}

	if (!observer0_attached && velocity > OBSERVER_ATTACH_VELOCITY) {
		motor0.linkSensor(&observer0);
		observer0_attached = true;

		// Give the sensor timing state a clean start if supported by your Sensor class.
		observer0.init();
		return;
	}
}
#endif

#if !DISABLE_MOTOR_1 && DISABLE_ENCODERS && !DISABLE_MXLEMMING_OBSERVER
static void update_motor1_observer_attachment() {
	const float velocity = observer1_attached
		? fabsf(motor1.shaft_velocity)
		: fabsf(motor1.target); // replace with requested velocity if target is not velocity

	if (observer1_attached && velocity < OBSERVER_DETACH_VELOCITY) {
		motor1.linkSensor(nullptr);
		observer1_attached = false;
		return;
	}

	if (!observer1_attached && velocity > OBSERVER_ATTACH_VELOCITY) {
		motor1.linkSensor(&observer1);
		observer1_attached = true;

		// Give the sensor timing state a clean start if supported by your Sensor class.
		observer1.init();
		return;
	}
}
#endif

static void init_motors() {
	Serial.begin(115200);

	SimpleFOCDebug::enable(&Serial);

	#if !DISABLE_MOTOR_0
		motor0.voltage_sensor_align = min(2.0f, USER_MAX_MOTOR_VOLTAGE);

		driver0.voltage_power_supply = USER_MAX_MOTOR_VOLTAGE;
		driver0.pwm_frequency = 50000;
		driver0.init();

		motor0.linkDriver(&driver0);

		motor0.voltage_limit = USER_MAX_MOTOR_VOLTAGE;
		motor0.current_limit = USER_MAX_MOTOR_CURRENT;

		motor0.useMonitoring(Serial);
		motor0.monitor_variables = _MON_TARGET | _MON_VEL | _MON_ANGLE | _MON_VOLT_Q | _MON_CURR_Q;

		#if BOARD_CURRENT_SENSE_TYPE == 0 && !DISABLE_CURRENT_SENSE
			currentSense0.linkDriver(&driver0);
			currentSense0.init();
			motor0.linkCurrentSense(&currentSense0);
		#endif

		#if !DISABLE_ENCODERS
			hall0.init();
			hall0.enableInterrupts(doHall0A, doHall0B, doHall0C);
			motor0.linkSensor(&hall0);
		#elif !DISABLE_MXLEMMING_OBSERVER
			motor0.sensor_direction = Direction::CW;
			motor0.zero_electric_angle = 0;

			// Start detached. It will attach once the requested velocity exceeds
			// OBSERVER_ATTACH_VELOCITY.
			motor0.linkSensor(nullptr);
			observer0_attached = false;
		#endif

		motor0.init();
		motor0.disable();

		#if !DISABLE_ENCODERS
			motor0.initFOC();
		#elif !DISABLE_MXLEMMING_OBSERVER
			// Temporarily attach for FOC initialization, then detach again.
			motor0.linkSensor(&observer0);
			observer0_attached = true;

			motor0.initFOC();

			motor0.linkSensor(nullptr);
			observer0_attached = false;
		#endif

		commander.add('A', doMotor0, motor0_label);
	#endif

	#if !DISABLE_MOTOR_1
		motor1.voltage_sensor_align = min(2.0f, USER_MAX_MOTOR_VOLTAGE);

		driver1.voltage_power_supply = USER_MAX_MOTOR_VOLTAGE;
		driver1.pwm_frequency = 50000;
		driver1.init();

		motor1.linkDriver(&driver1);

		motor1.voltage_limit = USER_MAX_MOTOR_VOLTAGE;
		motor1.current_limit = USER_MAX_MOTOR_CURRENT;

		motor1.useMonitoring(Serial);
		motor1.monitor_variables = _MON_TARGET | _MON_VEL | _MON_ANGLE | _MON_VOLT_Q | _MON_CURR_Q;

		#if BOARD_CURRENT_SENSE_TYPE == 0 && !DISABLE_CURRENT_SENSE
			currentSense1.skip_align = true;
			currentSense1.linkDriver(&driver1);
			currentSense1.init();
			motor1.linkCurrentSense(&currentSense1);
		#endif

		#if !DISABLE_ENCODERS
			hall1.init();
			hall1.enableInterrupts(doHall1A, doHall1B, doHall1C);
			motor1.linkSensor(&hall1);
		#elif !DISABLE_MXLEMMING_OBSERVER
			motor1.sensor_direction = Direction::CW;
			motor1.zero_electric_angle = 0;

			// Start detached. It will attach once the requested velocity exceeds
			// OBSERVER_ATTACH_VELOCITY.
			motor1.linkSensor(nullptr);
			observer1_attached = false;
		#endif

		motor1.init();
		motor1.disable();

		#if !DISABLE_ENCODERS
			motor1.initFOC();
		#elif !DISABLE_MXLEMMING_OBSERVER
			// Temporarily attach for FOC initialization, then detach again.
			motor1.linkSensor(&observer1);
			observer1_attached = true;

			motor1.initFOC();

			motor1.linkSensor(nullptr);
			observer1_attached = false;
		#endif

		commander.add('B', doMotor1, motor1_label);
	#endif
}

static void foc_timer_callback(void* /*arg*/) {
	#if !DISABLE_MOTOR_0
		#if DISABLE_ENCODERS && !DISABLE_MXLEMMING_OBSERVER
			update_motor0_observer_attachment();
		#endif

		motor0.loopFOC();
	#endif

	#if !DISABLE_MOTOR_1
		#if DISABLE_ENCODERS && !DISABLE_MXLEMMING_OBSERVER
			update_motor1_observer_attachment();
		#endif

		motor1.loopFOC();
	#endif
}

static void movement_timer_callback(void* /*arg*/) {
	#if !DISABLE_MOTOR_0
		motor0.move();
	#endif

	#if !DISABLE_MOTOR_1
		motor1.move();
	#endif
}

static void commander_timer_callback(void* /*arg*/) {
	#if !DISABLE_MOTOR_0
		//motor0.monitor();
	#endif

	#if !DISABLE_MOTOR_1
		//motor1.monitor();
	#endif

	commander.run();
}

static void start_motor_timers() {
	esp_timer_create_args_t foc_timer_args = {};
	foc_timer_args.callback = &foc_timer_callback;
	foc_timer_args.arg = nullptr;
	foc_timer_args.dispatch_method = ESP_TIMER_TASK;
	foc_timer_args.name = "foc_20khz";

	esp_timer_create_args_t movement_timer_args = {};
	movement_timer_args.callback = &movement_timer_callback;
	movement_timer_args.arg = nullptr;
	movement_timer_args.dispatch_method = ESP_TIMER_TASK;
	movement_timer_args.name = "movement_5khz";

	esp_timer_create_args_t commander_timer_args = {};
	commander_timer_args.callback = &commander_timer_callback;
	commander_timer_args.arg = nullptr;
	commander_timer_args.dispatch_method = ESP_TIMER_TASK;
	commander_timer_args.name = "commander_100hz";

	ESP_ERROR_CHECK(esp_timer_create(&foc_timer_args, &foc_timer));
	ESP_ERROR_CHECK(esp_timer_create(&movement_timer_args, &movement_timer));
	ESP_ERROR_CHECK(esp_timer_create(&commander_timer_args, &commander_timer));

	ESP_ERROR_CHECK(esp_timer_start_periodic(foc_timer, FOC_PERIOD_US));
	ESP_ERROR_CHECK(esp_timer_start_periodic(movement_timer, MOVEMENT_PERIOD_US));
	ESP_ERROR_CHECK(esp_timer_start_periodic(commander_timer, COMMANDER_PERIOD_US));
}

static void motor_init_task(void* /*arg*/) {
	init_motors();
	start_motor_timers();

	vTaskDelete(nullptr);
}

extern "C" void app_main(void) {
	xTaskCreatePinnedToCore(
		motor_init_task,
		"motor_init_task",
		8192,
		nullptr,
		3,
		nullptr,
		1
	);
}

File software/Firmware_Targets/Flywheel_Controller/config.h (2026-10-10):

#pragma once

#include <stdint.h>

#include <DShotRMT.h>

#include "../common/FaultManager/FaultManager.h"

namespace Flywheel_Controller {

static constexpr bool DEBUG = false;

// --------- I2C Settings ---------
static constexpr uint8_t I2C_ADDRESS = 0x62;

static constexpr uint32_t I2C_FREQUENCY = 400000;
static constexpr gpio_num_t SDA_PIN = GPIO_NUM_NC;
static constexpr gpio_num_t SCL_PIN = GPIO_NUM_NC;

enum I2C_ADDRESS_MAP : uint8_t {
    READY = 0x00, //R: tell if the peripheral is booted

    //generic diagnostics: bit (error ID - 1) is set in the error set.
    //  write an active error ID to ERROR_ID before reading its description.
    MASTER_ERROR = 0x01, //R: 1 when any error is active
    ERROR_SET_0 = 0x02, //R: bits 0-7 represent error IDs 1-8
    ERROR_SET_1 = 0x03, //R: bits 0-7 represent error IDs 9-16
    ERROR_SET_2 = 0x04, //R: bits 0-7 represent error IDs 17-24
    ERROR_SET_3 = 0x05, //R: bits 0-7 represent error IDs 25-32
    ERROR_ID = 0x06, //R/W: select an active error ID for description reads
    ERROR_REASON_LENGTH = 0x07, //R: length of the selected error description
    ERROR_REASON_START = 0x08, //R: reads the selected error description (read length bytes from here)

    FLYWHEELS_ARMED = 0x10, //R/W
    RPM_TARGET = 0x11, //R/W (float 4 bytes)
    ACTUAL_RPM = 0x15, //R (float 4 bytes): will always read 0 if bidirectional DShot is not available

    SOLENOID_ARMED = 0x19, //R/W
    SOLENOID_FIRE = 0x1A, //W
};

// --------- Fault Settings ---------
static constexpr uint8_t FAULT_I2C_INIT = 1;
static constexpr uint8_t FAULT_LEFT_ESC_INIT = 2;
static constexpr uint8_t FAULT_RIGHT_ESC_INIT = 3;
static constexpr uint8_t FAULT_SOLENOID_INIT = 4;
static constexpr uint8_t FAULT_LEFT_ESC_SIGNAL = 5;
static constexpr uint8_t FAULT_RIGHT_ESC_SIGNAL = 6;
static constexpr uint8_t FAULT_LEFT_ESC_TELEMETRY = 7;
static constexpr uint8_t FAULT_RIGHT_ESC_TELEMETRY = 8;
static constexpr uint8_t FAULT_INVALID_RPM_TARGET = 9;

using Controller_Fault_Manager = FaultManager<
    FaultCondition<"I2C init", FAULT_I2C_INIT>,
    FaultCondition<"L ESC init", FAULT_LEFT_ESC_INIT>,
    FaultCondition<"R ESC init", FAULT_RIGHT_ESC_INIT>,
    FaultCondition<"Solenoid init", FAULT_SOLENOID_INIT>,
    FaultCondition<"L ESC signal", FAULT_LEFT_ESC_SIGNAL>,
    FaultCondition<"R ESC signal", FAULT_RIGHT_ESC_SIGNAL>,
    FaultCondition<"L ESC telemetry", FAULT_LEFT_ESC_TELEMETRY>,
    FaultCondition<"R ESC telemetry", FAULT_RIGHT_ESC_TELEMETRY>,
    FaultCondition<"Invalid RPM", FAULT_INVALID_RPM_TARGET>
>;

using Controller_Fault_Id = Controller_Fault_Manager::FaultId;

inline Controller_Fault_Manager fault_manager;

static constexpr uint8_t ERROR_REASON_MAX_LENGTH = 127;

// --------- DSHOT Settings ---------
static constexpr gpio_num_t ESC_PINS[2] = {GPIO_NUM_NC, GPIO_NUM_NC};
static constexpr dshot_mode_t DSHOT_MODE = DSHOT600;
static constexpr uint32_t DSHOT_REFRESH_MS = 20;

static constexpr bool DSHOT_BIDIRECTIONAL = true;
static constexpr uint32_t RPM_TELEMETRY_TIMEOUT_MS = 500;

static constexpr uint16_t MOTOR_MAGNET_COUNT = 14;

static constexpr float RPM_PID_KP = 0.002f;
static constexpr float RPM_PID_KI = 0.0005f;
static constexpr float RPM_PID_KD = 0.0f;
static constexpr float RPM_PID_INTEGRAL_LIMIT = 100000.0f;

// --------- Solenoid Settings ---------
static constexpr gpio_num_t SOLENOID_PIN = GPIO_NUM_NC;
static constexpr bool SOLENOID_ACTIVE_HIGH = true;

static constexpr uint32_t SOLENOID_SHOT_TIME_MS = 100;

}; //namespace Flywheel Controller

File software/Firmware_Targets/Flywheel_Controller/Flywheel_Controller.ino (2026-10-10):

//This firmware is designed to run on an esp32 based microcontroller board using the Arduino framework
// It is in charge of controlling the flywheel ESCs based on I2C commands from the Jetson
// It controls two bluejay ESCs using bidirectional DSHOT and maintains precise RPM targets using a PID loop

#include <Arduino.h>

#include "config.h"
#include "ESC_Controller.h"
#include "I2C_Driver.h"
#include "Solenoid_Controller.h"

using namespace Flywheel_Controller;

static void halt_on_initialization_error() {
    if (DEBUG) Serial.println("Initialization failed. Halting...");

    while (true) {
        esc_controller.force_safe_state();
        solenoid_controller.force_safe_state();
        delay(1000);
    }
}

void setup() {
    if (DEBUG) {
        Serial.begin(115200);
        delay(500);

        Serial.println("DShotRMT Flywheel ESC Controller");
        Serial.println("Motors and solenoid off");
        SOLENOID_ACTIVE_HIGH ? Serial.println("Solenoid active high") : Serial.println("Solenoid active low");
        Serial.println("Starting...");
    }

    const bool i2c_success = initialize_i2c();
    const bool esc_success = esc_controller.begin();
    const bool solenoid_success = solenoid_controller.begin();

    if (!i2c_success || !esc_success || !solenoid_success) {
        halt_on_initialization_error();
    }

    I2C_Registers.ready = true;
}

void loop() {
    const uint32_t now = millis();

    esc_controller.update(now);
    solenoid_controller.update(now);
}

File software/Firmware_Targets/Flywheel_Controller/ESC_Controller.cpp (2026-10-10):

#include "ESC_Controller.h"

#include <Arduino.h>

#include <math.h>

#include "I2C_Driver.h"
#include "config.h"

namespace Flywheel_Controller {

static void reset_rpm_pid(RPM_PID &pid) {
    pid.integral = 0.0f;
    pid.previous_error = 0.0f;
    pid.last_update_ms = 0;
    pid.initialized = false;
}

static float update_rpm_pid(RPM_PID &pid, const float target_rpm, const float actual_rpm, const uint32_t now) {
    if (!isfinite(target_rpm) || target_rpm <= 0.0f) {
        reset_rpm_pid(pid);
        return 0.0f;
    }

    const float delta_time = pid.initialized ? static_cast<float>(now - pid.last_update_ms) / 1000.0f : static_cast<float>(DSHOT_REFRESH_MS) / 1000.0f;
    const float error = target_rpm - actual_rpm;
    const float derivative = pid.initialized && delta_time > 0.0f ? (error - pid.previous_error) / delta_time : 0.0f;

    const float candidate_integral = constrain(pid.integral + error * delta_time, -RPM_PID_INTEGRAL_LIMIT, RPM_PID_INTEGRAL_LIMIT);
    const float unconstrained_output = RPM_PID_KP * error + RPM_PID_KI * candidate_integral + RPM_PID_KD * derivative;

    //prevent the integrator from increasing while the output is saturated.
    const bool output_saturated_high = unconstrained_output >= 100.0f && error > 0.0f;
    const bool output_saturated_low = unconstrained_output <= 0.0f && error < 0.0f;
    if (!output_saturated_high && !output_saturated_low) {
        pid.integral = candidate_integral;
    }

    pid.previous_error = error;
    pid.last_update_ms = now;
    pid.initialized = true;

    //output between 0-100%
    return constrain(RPM_PID_KP * error + RPM_PID_KI * pid.integral + RPM_PID_KD * derivative, 0.0f, 100.0f);
}

static dshot_result_t send_esc_throttle(ESC &esc, const float throttle_percent) {
    if (!isfinite(throttle_percent) || throttle_percent <= 0.0f) {
        return esc.comm.sendThrottle(0);
    }

    return esc.comm.sendThrottlePercent(constrain(throttle_percent, 0.0f, 100.0f));
}

ESC::ESC(const gpio_num_t esc_pin)
    : pin(esc_pin),
      comm(esc_pin, DSHOT_MODE, DSHOT_BIDIRECTIONAL, MOTOR_MAGNET_COUNT) {}

ESC_Controller::ESC_Controller()
    : left_esc(ESC_PINS[0]),
      right_esc(ESC_PINS[1]) {}

ESC_Controller esc_controller;

bool ESC_Controller::begin() {
    bool success = true;

    if (left_esc.pin != GPIO_NUM_NC) {
        const dshot_result_t result = left_esc.comm.begin();
        if (!result.success) {
            dispatch_fault(FAULT_LEFT_ESC_INIT);
            success = false;
            if (DEBUG) Serial.println("Error: Left ESC init failed");
        }
    } else {
        dispatch_fault(FAULT_LEFT_ESC_INIT);
        success = false;
        if (DEBUG) Serial.println("Error: Left ESC control pin is not configured");
    }

    if (right_esc.pin != GPIO_NUM_NC) {
        const dshot_result_t result = right_esc.comm.begin();
        if (!result.success) {
            dispatch_fault(FAULT_RIGHT_ESC_INIT);
            success = false;
            if (DEBUG) Serial.println("Error: Right ESC init failed");
        }
    } else {
        dispatch_fault(FAULT_RIGHT_ESC_INIT);
        success = false;
        if (DEBUG) Serial.println("Error: Right ESC control pin is not configured");
    }

    if (!success) {
        return false;
    }

    initialized = true;
    if (DEBUG) Serial.println("ESCs initialized successfully...");
    return true;
}

void ESC_Controller::force_safe_state() {
    left_esc.armed = false;
    right_esc.armed = false;

    left_esc.throttle_percent = 0.0f;
    right_esc.throttle_percent = 0.0f;

    left_esc.rpm = 0.0f;
    right_esc.rpm = 0.0f;

    reset_rpm_pid(left_rpm_pid);
    reset_rpm_pid(right_rpm_pid);

    I2C_Registers.flywheels_armed = false;
    I2C_Registers.RPM_target = 0.0f;
    I2C_Registers.RPM_actual = 0.0f;

    event_manager.arm_escs = false;
    event_manager.disarm_escs = false;

    if (initialized) {
        left_esc.comm.sendThrottle(0);
        right_esc.comm.sendThrottle(0);
    }
}

void ESC_Controller::handle_arm_events(const uint32_t now) {
    // Disarm takes priority if arm and disarm arrive before this loop runs.
    if (event_manager.disarm_escs) {
        const bool was_armed = left_esc.armed || right_esc.armed;

        left_esc.armed = false;
        right_esc.armed = false;
        left_esc.throttle_percent = 0.0f;
        right_esc.throttle_percent = 0.0f;
        left_esc.rpm = 0.0f;
        right_esc.rpm = 0.0f;
        reset_rpm_pid(left_rpm_pid);
        reset_rpm_pid(right_rpm_pid);

        I2C_Registers.flywheels_armed = false;
        I2C_Registers.RPM_target = 0.0f;
        I2C_Registers.RPM_actual = 0.0f;

        if (was_armed && DEBUG) Serial.println("Flywheel ESCs disarmed; target cleared");
    } else if (event_manager.arm_escs) {
        const bool was_disarmed = !left_esc.armed || !right_esc.armed;

        left_esc.armed = true;
        right_esc.armed = true;
        I2C_Registers.flywheels_armed = true;
        left_esc.last_telemetry_ms = now;
        right_esc.last_telemetry_ms = now;
        left_esc.telemetry_received = false;
        right_esc.telemetry_received = false;
        reset_rpm_pid(left_rpm_pid);
        reset_rpm_pid(right_rpm_pid);

        if (was_disarmed) {
            I2C_Registers.RPM_target = 0.0f;
            if (DEBUG) Serial.println("Flywheel ESCs armed at zero throttle");
        }
    }

    event_manager.arm_escs = false;
    event_manager.disarm_escs = false;
}

void ESC_Controller::mark_dshot_error(const uint8_t fault_id, const char *message) {
    const bool first_error = !fault_manager.is_fault_active(fault_id);
    dispatch_fault(fault_id);

    if (DEBUG && first_error) Serial.println(message);
}
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

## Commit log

2026-03-02 An attempt at controlling the cameras, a merge fix for readme that i forgot, and some files for controlling.
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2026-04-07 Finished the data capture prototype tool and made a recording
    [pushup_test.csv]
2026-04-28 wrote the capture part of the pipeline in cpp
    [pushup_test.csv]
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2026-05-08 Add simpleFOC Dual Motor Controller KiCad files
    Add a complete KiCad project for the simpleFOC Dual Motor Controller: schematics (DriverStage, PoleDriver, main), PCB, project/prl/pro backup archives, symbol and footprint libraries (including easye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
    [DriverStage.kicad_sch, PoleDriver.kicad_sch, simpleFOC Dual Motor Controller.kicad_pcb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]
2026-05-09 High current drive routing
    Add TDSON-8 3D models and footprint (.step, .wrl, .kicad_mod) and update easyeda2kicad library; modify KiCad schematic sheets (DriverStage.kicad_sch, PoleDriver.kicad_sch, simpleFOC Dual Motor Contro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
    [DriverStage.kicad_sch, PoleDriver.kicad_sch, simpleFOC Dual Motor Controller.kicad_pcb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]
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2026-05-10 Improve sampling and add min detection area filter
    Refactor stratified sampling and add a min-det-area filter. Introduces helper functions (_target_counts, _take) and changes stratified_sample_items to accept background_candidates, background_ratio and to deterministically sample background, ball and other labeled images while filling shortfalls without exceeding max_images. convert_and_download_split now supports --min-det-area: images with any person/ball bbox below that area are rejected and removed from labeled/background pools. Also adds CLI arg --min-det-area, improves logging of selected counts, and cleans up shuffling/selection logic to make ratios (background and ball) apply to the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
2026-05-12 not sure why the schematic and pcb aren't syncing :(
    [simpleFOC Dual Motor Controller.kicad_pcb, simpleFOC Dual Motor Controller.kicad_sch]
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2026-05-13 swapped CPU for ESP32
    [simpleFOC Dual Motor Controller.kicad_pcb]
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2026-05-26 Add templated FaultManager for fault handling
    Introduce a templated FaultManager and supporting types to centralize fault condition handling. Adds FixedString and FaultCondition helpers and a FaultManager class (header + implementation) that provides per-fault storage, set/clear APIs, attachable per-fault and master callbacks, and helper dummy functions for compile-time-dispatched actions. The implementation includes compile-time checks (non-empty/null-terminated reason strings and unique fault IDs) and initializes an array of internal fault storage entries for the provided FaultCondition types. Intended to provide a safe, compile-time-configurable fault registry and callback dispatch mechan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
2026-05-29 Update motor configs and defaults
    Adjust motor test defaults and fix configuration/limits. Bump input_voltage to 15V; swap default enabled motor (disable MOTOR0, enable MOTOR1). Harmonize motor1 parameters (poles, resistance, KV, inductance) and increase per-motor current limits to 2.0A (introduce max_motor0_* and max_motor1_*). Disable encoders by default. Fix maximum_current variable names/types and correct PWM type check to use BOARD_PWM_TYPE == 3. Ensure motor setup uses the correct voltage/current limits for each motor. Add motor.characteriseMotor(2.0f) calls and disable motors after characterization in setup.
    [simpleFOCtester.ino]
2026-05-29 Update timing parameters to ensure ESP doesn't lock up
    [main.cpp]
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2026-06-02 Add ESP32 DShot ESC serial tester sketch
    Add an Arduino/ESP32 sketch (DShot_ESC_Tester.ino) that provides a serial-based controller for testing DShot ESCs using the DShotRMT library. Features configurable GPIO, DShot mode, bidirectional telemetry flag, and refresh interval; issues a safety stop on boot and repeatedly refreshes throttle frames. Supports serial commands: arm, disarm, beep (beacon), help, and numeric duty values 0-100 with validation and status/result reporting. Useful for bench testing and diagnosing ESC behavior via an ESP32.
    [DShot_ESC_Tester.ino]
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2026-06-05 Refactor DShot ESC tester for multi-ESC support
    Remove the old esp32-specific sketch and add a rewritten DShot_ESC_Tester.ino that supports an arbitrary number of ESCs via a constexpr ESC_PINS array. Replaces pointer-based per-ESC state with an Esc struct holding a DShotRMT member, uses compile-time template machinery to build the enabled-ESC array, and adds commands: per-motor selector (M#), 'a' for all, 'list' to show enabled ESCs, improved direction handling, and safety stops. Also changes default DSHOT_MODE to DSHOT600 and updates initialization/refresh logic and command reporting. Adds a static_assert to ensure at least one ESC is enabled.
    [DShot_ESC_Tester.ino]
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2026-06-06 cleaned up unused parts from the gimbal assembly
    [20223618_01.SLDPRT, 20223618_02.SLDPRT, ESSENTRA COMPONENTS 0146ef7a-e676-3b93-9c54-42d9e2b4027d.SLDASM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]
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2026-06-07 added a place to mount a driver board
    [Gimbal Swivel.SLDPRT]
2026-06-07 ensure that the PCB mount is printable without supports
    [Gimbal Swivel.SLDPRT]
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2026-06-12 Updated gimbal assembly base to fit the new motor
    [Gimbal Base.SLDPRT, Gimbal Swivel.SLDPRT]
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2026-08-26 Moved the solidworks assembly into a folder for the plastic version
    [Gimbal Assembly.SLDASM, Gimbal Base.SLDPRT, Gimbal Driver Mount.SLDPRT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]
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2026-08-31 designed a magnet holder for the pitch motor
    [Pitch Motor Magnet Plate.SLDPRT]
2026-08-31 started creating the mounting beam for the launcher
    [Launcher Assembly.SLDASM, Launcher I-Beam Mount.SLDPRT, Magnet Plate Spacer.SLDPRT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]
2026-09-02 Started prototyping the initial Motor Holding Tower Design for the wood base
    [Gimbal Assembly.SLDASM, Gimbal Swivel.SLDPRT, Launcher Assembly.SLDASM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]
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2026-09-11 Update gimbal wood parts and launcher assembly
    Refactors the gimbal CAD parts toward the wood configuration by removing older plate/spacer files, adding new wood-specific magnet and yaw components, and updating related pitch mounts and the gimbal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
    [Gimbal Base.SLDPRT, Launcher Assembly.SLDASM, Magnet Plate Spacer.SLDPRT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]
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2026-09-24 Removed the simple motor controller PCB project because it was never designed
    [DriverStage.kicad_sch, PoleDriver.kicad_sch, simpleFOC Single Motor Controller.kicad_pcb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]
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2026-09-24 Reorganize deprecated gimbal CAD models
    Moves deprecated gimbal SolidWorks files from `hardware/Gimbal` into `hardware/3D Models/Gimbal` to match the updated hardware directory structure. Also relocates `Magnet Plate Spacer.SLDPRT` into th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
    [Gimbal Assembly.SLDASM, Gimbal Pivot Holder.SLDPRT, Gimbal Swivel.SLDPRT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]
2026-09-24 Reduce hall averaging samples to 4
    Lower the analog hall sensor averaging window in `readAnalogMillivoltsAveraged()` from 8 to 4 samples. This reduces ADC read latency so the closed-loop hall test can respond faster, while still keeping basic noise smoothing.
    [Closed_Loop_Analog_Hall_Test.ino]
2026-09-24 Reorganize CAD assets under 3D Models
    Moves existing SolidWorks hardware files into a unified `hardware/3D Models` directory structure (Gimbal, Launcher, Mounts, and Power Supply) and adds new CAD parts/assemblies for the gimbal, launche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
    [Box Bottom.SLDPRT, Box Top.SLDPRT, Flywheel Assembly.SLDASM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]
2026-09-24 Add Jetson Orin Nano case models
    This change adds the 3D printable Jetson Orin Nano enclosure files for the bottom shell and main case body, including the no-CAN/no-inserts variant. These model files support the project’s hardware e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
    [Orin_nano_case_bottom.3MF, Orin_nano_case_main_No_CAN_No inserts.3MF]
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2026-09-24 Created a solidworks part that matches the wood base of the device
    For completeness
    [Base.SLDPRT]
2026-09-29 Rename Zed mount assembly file
    Renames the Zed mount SolidWorks assembly file to use the correct singular naming convention and avoid confusion with the existing mount naming.
    [Zed Mount.SLDASM]
2026-09-29 Update ZED mount hardware
    Refine the ZED cage and angle gauge CAD parts for the mount assembly. This update adjusts the modeled geometry to improve fit and alignment in the ZED mounting setup.
    [ZED Cage.SLDPRT, Zed Angle Guage.SLDPRT]
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2026-09-29 Created a center indicator so we can center the mount on the wood
    [Telescoping Center Indicator.SLDPRT]
2026-09-29 fixed tolerances on the ZED angle mount
    [ZED Cage.SLDPRT, Zed Angle Guage.SLDPRT]
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2026-09-30 Finalized Internal Hole Depth for better clearance
    [Zed Angle Guage.SLDPRT]
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2026-09-30 cutout ball portion of barrel
    Still need to add slots for the servos to hold the ball in place while it is not in motion. Still need to add a hole for the solenoid.
    [Barrel.SLDPRT]
2026-10-01 move ZED model to correct folder
    [ZED2i.step]
2026-10-01 Add cutout for ZED clearance to ZED mount
    [MirrorZed Angle Guage.SLDPRT, ZED Cage.SLDPRT, Zed Angle Guage.SLDPRT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]
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2026-10-06 Created loader stop with 3 geometric options depending on angle (1) Lock ball in 3D, (2) Lock ball in Z, (3) Lock ball in x
    [Loader Assembly.SLDASM, Loader Stop.SLDPRT, Stager.SLDPRT]
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2026-10-07 Changed the mounting method for the flywheel rail in order to ensure that all the screws fit and parts can go together
    [Flywheel Motor Mount.SLDPRT, Flywheel Rail.SLDPRT, Launcher Assembly.SLDASM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]
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2026-10-07 created a mount for the solenoid and added it to the assembly
    [Launcher Assembly.SLDASM, Loader Assembly.SLDASM, Solenoid Mount.SLDPRT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]
2026-10-08 added fan blades to the flywheel mounts in order to cool flywheel motors
    [Flywheel Wheel Mount.SLDPRT, Launcher Assembly.SLDASM, Loader Assembly.SLDASM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]
2026-10-08 made the flywheel mounts smooth so that they can spin through the air easier and mirrored it in the assembly so that the air is blown the correct direction
    [Flywheel Wheel Mount.SLDPRT, Launcher Assembly.SLDASM, Loader Assembly.SLDASM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]
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2026-10-08 Decreased bearing and wheel tolerances for less wobble
    [Flywheel Wheel Mount.SLDPRT, Launcher Assembly.SLDASM, MirrorFlywheel Wheel Mount.SLDPRT]
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2026-10-10 made the slip ring thicker so it doesn't get stuck to the print bed
    [Slip Ring Hole Guide.SLDPRT]
2026-10-10 Add ESP32 flywheel controller firmware
    Adds a new Flywheel_Controller firmware target with initial Arduino/ESP32 implementation files. The change introduces I2C register/event handling, dual ESC control over DShot (including bidirectional telemetry support), RPM target tracking with PID control scaffolding, and solenoid arm/fire timing logic with safety/error state propagation.
    [Flywheel_Controller.ino, I2C_Driver.cpp, config.h]
2026-10-10 Unify controller faults via FaultManager
    Replaces ad-hoc ESC/solenoid error bits with centralized fault dispatch and tracking. I2C now exposes generic fault diagnostics (master flag, 32-bit active fault set, selected fault ID, and fault reason text), and ESC/Solenoid initialization/runtime paths now report faults through `dispatch_fault`, including telemetry/signal failures and invalid RPM targets.
    [ESC_Controller.cpp, I2C_Driver.cpp, I2C_Driver.h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]
2026-10-13 Switch screencap grabber to native ZED YOLO
    Replaces the custom TensorRT/PyCUDA inference and manual decode pipeline with ZED SDK native custom YOLO ONNX detection/tracking. Adds a CLI-driven runtime (`--onnx`, `--confidence`, `--dynamic-input-size`, `--no-display`, `--static-camera`, `--svo`), class-specific confidence filtering (ignore person, track ball), tracked-object logging, and optional OpenCV visualization of ball boxes/IDs/confidence.
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2026-10-13 Removed the dual motor controller because it is no longer a part of the project
2026-10-13 Optimize NNX models and adjust depth
    Adds lazy ONNX model simplification via a new --optimize-onnx flag, caching the generated optimized model for later runs and surfacing a helpful install error if onnxsim is unavailable. Also updates ZED camera initialization to use NEURAL_LIGHT depth mode for improved runtime depth behavior.
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2026-10-13 Optimize 3D projectile trajectory rendering
    Reworks trajectory fitting to use a gravity-constrained model in relative time, then maps back to absolute-time coefficients for compatibility. This improves numerical stability and reduces per-frame fitting cost by limiting candidate windows and dropping redundant gravity checks. The visualization is replaced with a lightweight orthographic 3D view (grid, axes, projected tracks, dashed predictions), and display rendering is decoupled from camera ingest via a configurable `--display-fps` cap plus stale-track pruning to keep runtime responsive.
2026-10-13 Optimize existing ZedHandler for high-rate ball tracking
    - Keep get_objects() focused on the 100 Hz tracking path
    - Remove unused velocity processing from tracked object output
    - Move image retrieval and 2D bounding-box processing to get_frame()
    - Lazily allocate and reuse a single debug image buffer
    - Preserve stable object IDs across temporary ZED SDK ID changes
    - Improve 3D reassociation behavior after short tracking gaps
    - Handle temporary invalid depth without unnecessarily breaking tracks
    - Add cached camera intrinsics for trajectory projection
    - Add optional SDK and total get_objects() timing measurements
    - Reduce unnecessary allocations and NumPy work in identity tracking
    - Prune sta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
2026-10-13 Refactor ballistic tracking and camera overlay
    Reworked `projectileMotion.py` into a fixed-gravity trajectory module plus a live tracker/overlay pipeline. Added typed dataclasses (`TrajectoryFit`, `BallMeasurement`, `BallTrack`) and a reusable `fit_trajectory` API with strict timestamp/position validation and RMS error scoring.
    Replaced the old standalone 3D render path with image-space overlay on the ZED frame: projected measured trails, dashed future predictions, detection boxes, and per-track fit stats. Updated `main` to use `grab_and_get_objects`, per-ID track pruning, optional headless mode, and richer CLI controls (confidence, dynamic input size, static camera, stale-track timeout, di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
2026-10-13 Fit trajectories in ZED gravity-aligned world coordinates
    - Configure ZED positional tracking to align the world frame with gravity
    - Return tracked ball positions in the ZED WORLD reference frame
    - Keep projectile fitting entirely in gravity-aligned world coordinates
    - Use fixed gravity along world -Y instead of assuming the camera is level
    - Add current camera pose access for visualization
    - Transform predicted world-space trajectories back into camera coordinates before projection
    - Keep camera pose lookup and image projection out of the 100 Hz tracking hot path
    - Remove camera-depth assumptions from world-space trajectory validation
    - Hide predicted trajectories when camera pose tracking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
2026-10-13 Gate projectile fits until gravity stabilizes
    Adds a gravity-alignment warmup period before collecting trajectory samples, resets state on timestamp rollback, and rejects impossible per-frame speed jumps to avoid bad world-frame data. Refactors projectile classification to compare ballistic vs linear motion on the vertical axis, loosens/tunes fit thresholds and windowing, and returns explicit fit-status reasons that are shown in the overlay when prediction is unavailable.
2026-10-13 Tune ZED tracking for projectile fitting
    Adjusts ZED object tracking and depth settings to better support fast thrown-ball trajectories: disables grounded/static assumptions, reduces tracker smoothing, and enables moderate depth stabilization. In projectile fitting, adds per-axis RMS residual tracking, applies axis-specific fit thresholds (with looser depth tolerance), ignores non-OK ZED tracking states as observations, and updates status/overlay messaging to expose ballistic and XYZ fit quality.
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2026-10-15 added comments, error getters, and worker thread start/stop controls
    Add explicit worker thread start/stop controls, improve transaction and driver documentation, support registerless transactions with nullable register addresses, and expose thread-safe device error polling and retrieval.
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2026-10-15 Refactor flywheel I2C fault reporting and ensure it compiles
    Route controller safety checks through Fault_Manager, expose active fault data through the revised I2C register layout, and support multi-byte RPM and error-reason reads. Update Jetson error-bit decoding to match one-based fault IDs.
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2026-11-06 Update DShot ESC tester includes
    Replace the DShotRMT header include with the required DShot definitions, utilities, and initialization source files for the ESC tester.
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2026-11-07 Renamed solenoid pin to fix capitalization
2026-11-07 Fixed solenoid pin clearance and made hole for lever to hit the ball
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2026-11-09 small fixes to allow file to run on Jetson, should be ready to use when launcher is deployed
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2026-11-10 made some whoopsies last commit (made passed values python floats, redid the CSS for the button again, bugfixing an issue with camera freezes when ball detection
2026-11-10 doing a lot of commits today to deploy files to the Jetson. Just some more fixes, and terminal surpression.
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2026-11-12 added solenoid firing mechanism, now interfaces with I2C driver of launch controller. Need to update has_fired and reset it with an update to webpage.py, but afterwards is full I2C pipeline testing
2026-11-12 some udpates to the webpage to allow for a RESET function. Updated Firing function for safety; arm-solenoid can only be called once from BANG.py.
